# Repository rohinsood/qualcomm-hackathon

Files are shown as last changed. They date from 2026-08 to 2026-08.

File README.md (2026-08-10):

# Lighthouse 🔦 | Qualcomm Multiverse Hackathon Finalist

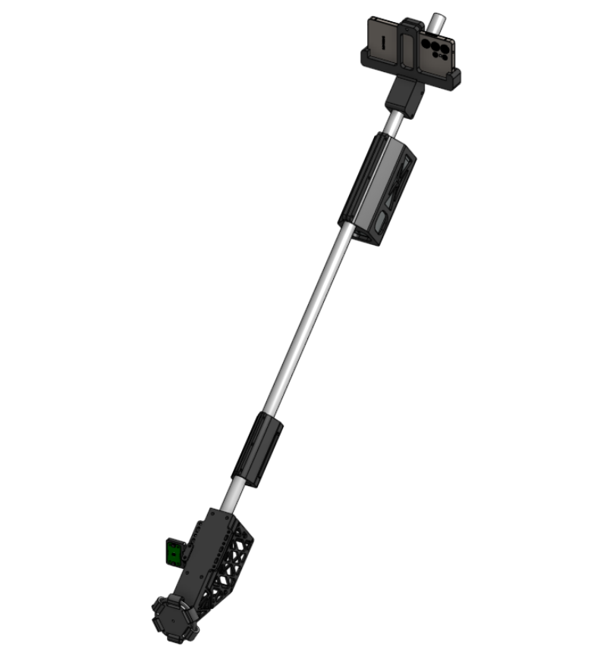
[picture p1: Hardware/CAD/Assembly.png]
|  |  |
:-------------------------:|:-------------------------:

**An open-source self-steering white cane powered by on-device AI.**

A 3D-printed omni wheel at the cane tip physically steers the user around
obstacles and along walking routes. All AI runs on Qualcomm silicon — no cloud,
no subscription, no signal required. Built, printed, assembled, and walked with.

**Demo Video**

https://github.com/user-attachments/assets/4f166f12-43d0-46fc-8983-bd9591bafe06

**Snapdragon Multiverse Hackathon 2026** · Qualcomm San Diego

| | |
|---|---|
| **~$196 total** | Excluding the phone. Commercial smart canes: $800–$1,150 |
| **No depth sensor** | Monocular metric depth on the Hexagon NPU replaces a LiDAR unit |
| **Fully offline** | Airplane mode changes nothing about obstacle avoidance |
| **AI across the Qualcomm multiverse** | Phone NPU/GPU + board CPU, running 8 models across 2 Snapdragon SoCs simultaneously |
| **Open source** | Code, CAD, BOM, wiring — AGPL-3.0 |

---

## Team

| Name | Github |
|---|---|
| Rohin Sood | https://github.com/rohinsood |
| Manuel Rodriguez | https://github.com/MaRodriguezB777 |
| Venkata Yaswanth Kanduri | https://github.com/kvyaswanth |
| Noah Zhang | https://github.com/iujab |

---

## Why this exists

250 million people live with impaired vision. A white cane costs $20 and tells
you nothing until you hit something. A guide dog costs $50,000 and has a
multi-year waitlist. Most electronic aids beep or buzz — interpreting that costs
time and attention at the exact moment you have neither.

Lighthouse **steers**. A motorized wheel nudges your hand toward the clear path.
You keep walking. The cane handles the geometry.

The key insight: steering the hand through the cane — grounded kinesthetic
feedback — guides people more accurately and with lower cognitive load than audio
or vibration cues. The NPU is what makes it possible to do the perception for
that steering on a phone, at the cadences required, on a battery.

---

## Accessibility first

- **Degrades to a white cane.** If every electronic system fails, contact sensing
  still works. The familiar form is kept deliberately.
- **Steering, not beeping.** Hearing stays free for traffic and conversation.
- **Offline by default.** No account, no connectivity, no privacy cost.
- **Private by construction.** Camera, audio, and location never leave the device.
- **Power on and walk.** No configuration needed to avoid obstacles.
- **Printable.** No proprietary parts. Break a piece, print another.
- **Refuses rather than guesses.** No corridor found → STOP, not a random direction.

---

## Edge AI on the Qualcomm stack

AI runs on **two Qualcomm SoCs simultaneously** — the phone's Snapdragon 8 Elite
(NPU + GPU) handles high-framerate vision, while the Arduino UNO Q's Dragonwing
QRB2210 (4×A53 CPU) runs a terrain classifier and a depth navigator on a
downward-facing camera at the cane handle. Different models, different devices,
different parts of the problem — all on Qualcomm silicon, all offline.

### Models running across the system

**Phone — Snapdragon 8 Elite (Hexagon NPU + Adreno GPU):**

| Model | What it does | Cadence | Accelerator |
|---|---|---|---|
| **Depth-Anything-V2-Metric-Small** | Per-pixel distance in meters | ~3 Hz | QNN → Adreno GPU / Hexagon NPU |
| **FFNet-78S-LowRes** (Cityscapes) | Walkability segmentation, outdoor | every frame | QNN → Hexagon NPU |
| **SegFormer-B0** (ADE20K) | Walkability segmentation, indoor | every frame | QNN → Hexagon NPU |
| **YOLOv8n** | Object detection + depth-scale calibration | 1 Hz | QNN EP |
| **Qwen3.5-2B** (Q4_0 GGUF) | On-device scene companion | on request | GenieX → Hexagon NPU |
| **Kokoro-82M** | Neural text-to-speech | on utterance | sherpa-onnx, CPU |

**Board — Dragonwing QRB2210 (4×Cortex-A53 @ 2 GHz):**

| Model | What it does | Cadence | Runtime |
|---|---|---|---|
| **Places365 ResNet18** | Terrain classification → 6-class taxonomy | ~2.3 fps | ONNX Runtime, CPU |
| **Depth-Anything-V2-Small** (126×126) | Ground-cam depth navigator | ~2.2 fps | ONNX Runtime, CPU |

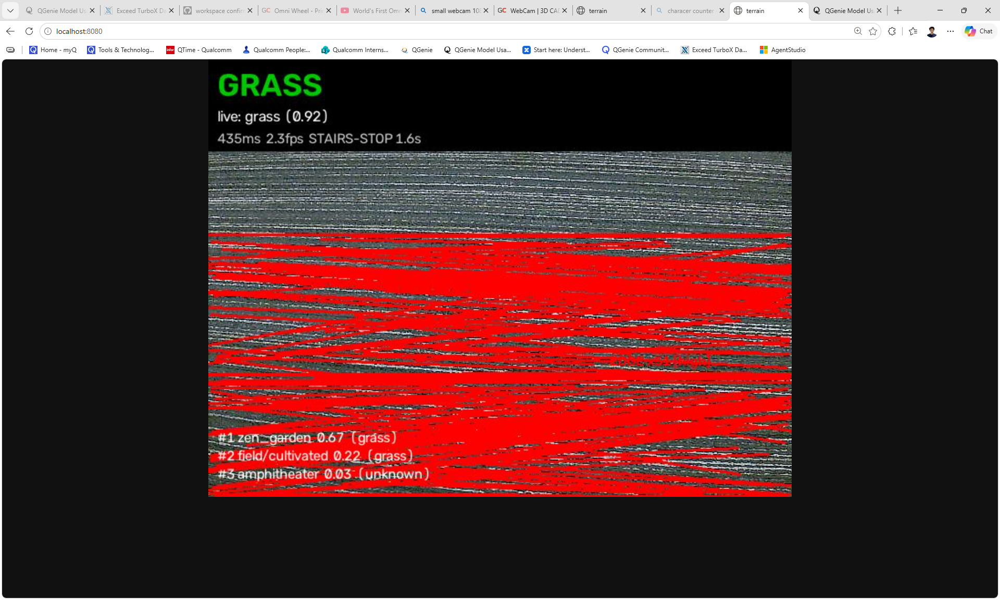
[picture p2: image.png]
Terrain classifier live


*Terrain sensor running on the UNO Q: Places365 classifying the ground surface
(GRASS, 0.92 confidence) at 435 ms / 2.3 fps, with Canny+Hough stair-edge
overlay in red. On a stairs detection, the wheel stops immediately and holds for
3 seconds — regardless of what the phone is asking for.*

### The terrain sensor — board-side AI that overrides the phone

The board's downward camera runs a **Places365 ResNet18** scene classifier
aggregated into a 6-class terrain taxonomy:

| Class | Meaning | Action |
|---|---|---|
| `sidewalk` | Walkable outdoor surface | → phone: OUTDOOR MODE |
| `road` | Vehicular surface | warn — user shouldn't be here |
| `grass` | Natural terrain | → phone: OUTDOOR MODE |
| `stairs` | Staircase / escalator / drop-off | **IMMEDIATE WHEEL STOP + 3 s hold** |
| `indoor_floor` | Interior walking surface | → phone: INDOOR MODE |
| `unknown` | Ambiguous | no action |

The stair-edge detector is a second signal: Canny + probabilistic Hough on the
lower 60% of the frame, looking for ≥5 parallel near-horizontal edges within 30%
of frame height. When it fires alongside the classifier, confidence is HIGH and
the stop is non-negotiable.

This is the one board-side motor command that **overrides the phone's steering
authority**. The phone drives the wheel left/right/clear — but STAIRS STOP takes
priority, because a staircase detected from the ground-facing camera is a
near-immediate hazard that the forward-facing phone may not see until the user is
at the edge.

The terrain label also **automatically switches the phone's nav mode** —
indoor_floor → indoor models (SegFormer + Hypersim depth), sidewalk/grass →
outdoor models (FFNet + VKITTI depth). No manual toggle needed.

### Accelerator allocation

```
QNN config: soc_model=69, htp_arch=79, burst mode, fp16
Fallback:   strict → mixed → CPU (never crashes, always runs)
```

**Vision takes the GPU first.** Not because it's faster — but because the
companion SLM decodes on the Hexagon NPU, and contending for it stalls the
safety-critical steering loop. Giving vision the Adreno GPU and reserving the NPU
for language keeps the critical path deterministic. This only matters when you're
running 6 models concurrently on one SoC.

**Domain-matched segmentation, not an ensemble.** FFNet-78S is trained on
Cityscapes (roads, sidewalks, curbs). SegFormer-B0 is trained on ADE20K (indoor
floors, doors, furniture). Running both every frame and merging was the earlier
design — it averaged away the specialization. Selecting one per nav mode halves
the compute for no measurable loss.

### Measured on-device

| What | Device | Result |
|---|---|---|
| Companion SLM first token (Qwen3.5-2B, Hexagon) | S25 Ultra | **186 ms** |
| Companion SLM decode rate | S25 Ultra | **12.1 tok/s** |
| Terrain classifier (Places365 ResNet18) | UNO Q | **435 ms / 2.3 fps** |
| Depth navigator (DA-V2, 126×126) | UNO Q | **452 ms / 2.2 fps** |
| Depth at higher res (DA-V2, 252×252) | UNO Q | 1728 ms — too slow for steering |
| MiDaS int8 on CPU | UNO Q | 1001 ms — **slower than float** (no NPU = dequant overhead) |

The board rows show why the split exists: the UNO Q runs terrain classification
and near-field depth at viable rates, but the high-res depth needed for corridor
planning at >3 Hz requires the phone's NPU. Each device does what it's good at.

### Qualcomm tooling

| Tool | Role |
|---|---|
| **QNN / QAIRT EP** | All phone vision inference, three-tier fallback |
| **Qualcomm AI Hub** | Sourced FFNet-78S and SegFormer-B0 |
| **GenieX** | On-device LLM runtime (Qwen3.5-2B) |
| **QUAD MCP** | Profiled models on real silicon over ADB |
| **Hexagon NPU** | Seg, depth, SLM decode on the phone |
| **Adreno GPU** | Vision (preferred tier) on the phone |
| **Arduino UNO Q** (Dragonwing QRB2210) | Terrain classification + ground-cam depth + actuation |
| **ONNX Runtime on QRB2210** | Board-side inference (Places365, DA-V2) at ~2.3 fps |
| **Arduino UNO Q** (Dragonwing QRB2210) | Cane board — sensing and actuation |

---

## How it works

```
Galaxy S25 Ultra — Snapdragon 8 Elite
  │
  ├─ Camera ~11 Hz → gravity-upright → 640×640 letterbox
  │    ├─ Depth-Anything-V2  @~3 Hz   metric depth (meters)
  │    ├─ Walkability seg    per-mode  FFNet outdoor / SegFormer indoor
  │    └─ YOLOv8n            @1 Hz    labels + depth-scale cal
  │         │
  │         └─ TraversabilityGrid  61×60 @ 0.1 m  log-odds  self-calibrating ground
  │              │
  │              └─ PolarPlanner  37 sectors ±90°  path-first  hysteresis
  │                   │
  │                   └─ CommandAggregator  200 ms vote → one letter
  │
  ├─ CompassNav  GPS + heading → goal bearing (Google routes or beeline)
  │
  └─ BLE ──► Arduino UNO Q — Dragonwing QRB2210
               ├─ Modulino Motors → omni wheel steers
               ├─ Modulino Distance → near-field STOP
               ├─ Modulino Vibro → haptic alert
               ├─ Ground camera → terrain.py (Places365 ResNet18)
               │    sidewalk/grass → OUTDOOR MODE
               │    indoor_floor → INDOOR MODE
               │    stairs → IMMEDIATE STOP + 3 s hold
               ├─ Ground camera → navigator.py (DA-V2 depth, 7-column)
               └─ 2 s failsafe
```

### Path-first planning

The planner is a **pass-through by default** — the route owns the heading.
Avoidance engages only when a ±10° cone around the goal is blocked.

- **Hysteresis:** blocks at 1.8 m, unblocks at 2.2 m — can't flip frame to frame
- **Committed heading:** `W_PREV = 1.6` > `W_GOAL = 1.0` > `W_WIDTH = 0.8` — the
  biggest weight resists changing its mind, which kills left-right oscillation
- **Asymmetric:** slow to leave the route (0.35), quick to return (0.45)
- **Refuses rather than guesses:** no corridor + no walkable columns → STOP

### Screen-thirds spoken guidance

An independent fallback, parallel to the planner: middle third decides whether
you can proceed, better outer third becomes the latched dodge side, spoken aloud
on each transition. Reuses data the pipeline already computes — no grid, no
planner involved.

---

## Hardware

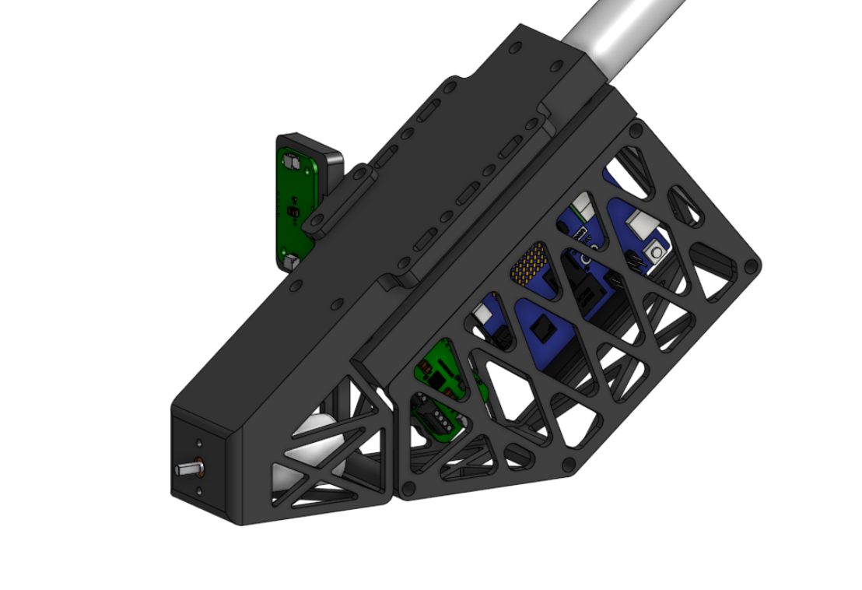
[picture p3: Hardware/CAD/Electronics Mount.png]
Electronics mount


Built, assembled, and walked with. ~$196 in parts, excluding the phone.

```
UNO Q ──► Modulino Motors ──► Modulino Vibro ──► Modulino Distance
```

| | |
|---|---|
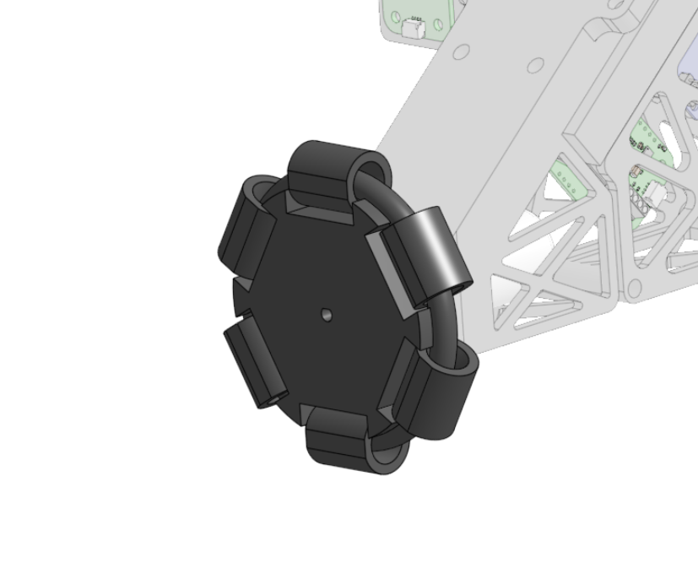
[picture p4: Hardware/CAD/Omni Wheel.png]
Omni wheel
|  | **Print-in-place omni wheel** — 6 rollers captive in the hub. No bearings, no assembly. Based on [this GrabCAD design](https://grabcad.com/library/omni-wheel-print-in-place-1), adapted for the JGA25 shaft. |
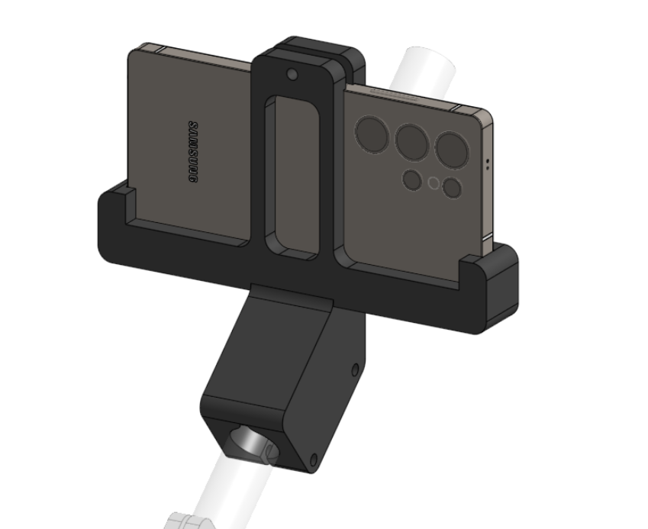
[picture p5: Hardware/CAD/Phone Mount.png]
Phone mount
|  | **S25 Ultra cradle** — pivoting hinge, rear cameras forward. |
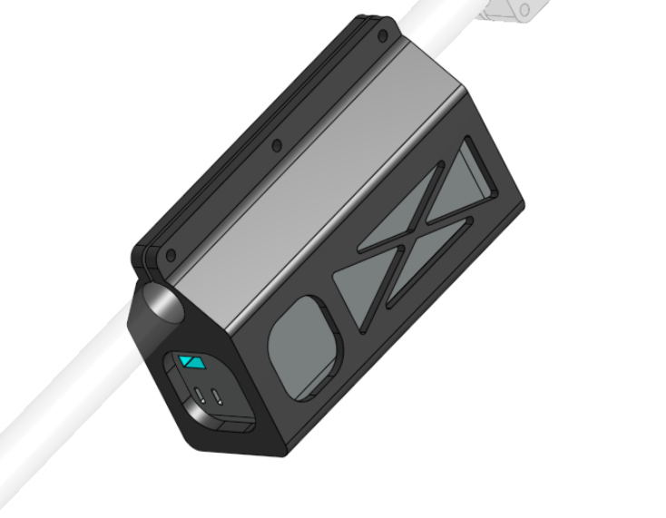
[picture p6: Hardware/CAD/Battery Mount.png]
Battery mount
|  | **Anker 737 cradle** — powers the board, charges the phone. |

**CAD source (Onshape):**
[open the live document](https://cad.onshape.com/documents/c0b905e8d1b94a52d9e9ca97/w/f6521fb190a4be4abaa604ca/e/e523a5a009f76747b4bb6591)

Full BOM and assembly: [`Hardware/`](Hardware/)

---

## Getting started

```bash
git clone https://github.com/<your-account>/lighthouse.git
cd lighthouse
git checkout v3
```

```bash
./gradlew :app:testDebugUnitTest     # 10 test classes, no device needed
./gradlew :app:installDebug
```

Models (depth + seg) must be pushed separately — see [`docs/MODELS.md`](docs/MODELS.md).
Board setup: [`docs/BOARD.md`](docs/BOARD.md).
Full from-scratch walkthrough: [`docs/SETUP.md`](docs/SETUP.md).

`main` also carries a merged demo (qhackGPS navigator + camera scan toggle) —
see [`docs/BRANCHES.md`](docs/BRANCHES.md).

---

## Repository layout

| Branch | What |
|---|---|
| **`main`** | Docs + hardware + merged demo app (qhackGPS + camera scan + voice) |
| **`v3`** | Full perception system — seg, depth, BEV grid, polar planner, SLM |
| `qhackfinal`, `qhackgps` | Nav prototypes and their lineage |

---

## Performance

| Parameter | Value |
|---|---|
| Perception cadence | 90 ms (~11 Hz) |
| Depth inference | 300 ms (~3 Hz) |
| Detection | 1000 ms (1 Hz) |
| Motor decisions | 200 ms (5 Hz) |
| Board failsafe | 2 s silence → motor stops |

Instrumented per-frame: `adb logcat -s ShepherdTime`

---

## Safety

**Research prototype. Not a sole mobility aid. Test with a sighted companion.**

| Guard | Threshold |
|---|---|
| Board motor failsafe | 2 s |
| Phone STOP on stalled vision | 600 ms |
| BLE write-stall teardown | 4 s |
| Planner can't find corridor | immediate STOP |

---

## Roadmap

**Done:** metric depth on NPU · domain-matched seg · BEV log-odds grid ·
path-first planner · walking routes + reroute · BLE steering · near-field ToF ·
terrain classification with stair-edge detection · automatic indoor/outdoor mode
switching · ground-cam depth navigator · neural TTS · on-device STT · OCR ·
screen-thirds spoken guidance · 2B companion on Hexagon · full CAD · cane built
and walked with

**Next:** end-to-end latency measurement · battery life characterization ·
companion model thermal gating · moving-obstacle prediction · user evaluation

---

## Prior work and acknowledgments

The steering concept — a motorized omni wheel applying grounded kinesthetic
feedback — is based on:

> P. Slade, A. Tambe, M. J. Kochenderfer, "Multimodal sensing and intuitive
> steering assistance improve navigation and mobility for people with impaired
> vision," *Science Robotics* **6**(59), eabg6594 (2021).
> [doi:10.1126/scirobotics.abg6594](https://doi.org/10.1126/scirobotics.abg6594)

Their study showed +18% walking speed for participants with impaired vision vs. a
white cane. Those are their results for their device — not a claim about ours.
Lighthouse is an independent implementation, not affiliated with the authors or
Stanford.

Also: [GrabCAD print-in-place omni wheel](https://grabcad.com/library/omni-wheel-print-in-place-1) ·
Qualcomm (NPU, QNN, AI Hub, GenieX, QUAD) · Arduino (UNO Q, Modulinos) ·
Depth-Anything-V2, FFNet, SegFormer, ONNX Runtime, sherpa-onnx.

## License

**AGPL-3.0** — see [`LICENSE`](LICENSE). Set by the bundled YOLOv8n detector.
Full reasoning: [`NOTICE.md`](NOTICE.md).

Open hardware, open software. Build it, change it, share it.

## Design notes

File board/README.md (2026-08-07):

# Cane board (Arduino UNO Q)

One app runs the whole cane: **`distance-watch/`** — phone-steered wheel,
obstacle haptics, LED-matrix status, and a live web dashboard. This is the
merged v3 firmware (wheel + three Modulinos + dashboard) carried onto the
qhackGPS/qhackcane pairing: the phone side here is **qhackGPS** (repo root),
talking over the Nordic UART bridge.

- **Wheel**: spins left/right on phone command or the dashboard buttons
  (dashboard always drives full scale). The 13×8 LED matrix mirrors the
  motion.
- **Vibro buzz**, parking-sensor style: pulses start at a 700 ms rhythm at
  the presence threshold (default 300 mm) and tighten to 250 ms as the
  obstacle closes; at/below 250 mm the buzz goes **continuous** ("stop now").
- **QCane Link dashboard** (port 7000): per-Modulino cards — distance
  readings (mm/cm, rate, age), motor telemetry with **live graphs** of
  sensed current (mA) and applied voltage (duty × VM, VM = 5 V), vibro
  state, Bluetooth links, rolling event log — plus manual spin/stop/buzz
  and clear-graphs buttons. Laptop arrow keys drive too: hold ← / → to
  spin (release stops), ↓/Space stops, ↑ buzzes.
- **Failsafe**: the Linux side re-sends the desired state 4×/s; if that
  stream stops for 2 s, the sketch stops the wheel and vibro on its own.

## Hardware

Modulinos daisy-chained on the Qwiic connector (`Wire1`), in wiring order:

```
UNO Q ──▶ Modulino Motors ──▶ Modulino Vibro ──▶ Modulino Distance
```

Chain order does not matter on I²C — each node answers on its own address.

**Motor wiring (important):** the motor sits across screw terminals
**`1A` + `2A`** — one half-bridge from **channel A** and one from
**channel B**, not a single channel's own pair, so the sketch drives the two
channels in opposite phase (`driveMotor()`); both channels show current
while it spins. `motor_selftest` re-measures every drive option if the
wiring is ever in doubt. Motor power goes into the `VM` + `GND` screw
terminals (5 V here); the yellow VM LED confirms power.

## How it works

```
Modulino Distance ──I²C──▶ MCU sketch ──"distance_reading"──▶ Python ──WebSocket──▶ dashboard
Modulino Motors + Vibro ◀──I²C── MCU sketch ◀──"set_wheel"/"set_vibro" heartbeat── Python
                                                                 ▲
                                                   HTTP :7000 (poll + POST)
                                                                 ▼
qhackGPS phone (BLE central) ◀──Nordic UART──▶ ble-bridge/ble_bridge.py (host daemon)
```

- `distance-watch/sketch/sketch.ino` — owns all three Modulinos: streams
  each valid ToF measurement, applies wheel commands (opposite-phase drive +
  matrix animation + `wheel_applied` acks), pulses the vibro, sends 2 Hz
  `motor_telemetry` and 1 Hz status heartbeats, and runs the motor
  self-test on request.
- `distance-watch/python/main.py` — the policy layer: presence
  (`mm <= threshold`) drives the vibro; the last wheel command (phone or
  dashboard, last writer wins) drives the motor; both re-sent 4×/s as the
  failsafe heartbeat. Serves the dashboard, REST API, event log, and graph
  history.
- `ble-bridge/` — host-side Nordic UART bridge + auto-accept pairing agent
  (systemd user services). The phone's texts steer the wheel (table below)
  and its 5 s heartbeat feeds the dashboard's Bluetooth card.
- `distance-watch/host/qcane_btd.py` — optional QCane GATT/SPP daemon from
  the v3 wheel board (speeds 1–5, `left`/`right 4`/JSON). Not needed for
  qhackGPS; the app's socket client simply reports "not running" until the
  daemon is started. Contract: `distance-watch/README.md`.

## Bluetooth (qhackGPS phone link)

`ble-bridge/ble_bridge.py` runs **on the Linux host** as a systemd *user*
service and exposes a standard **Nordic UART Service** peripheral named
**"Distance Watch"**:

| | UUID |
|---|---|
| Service (NUS) | `6E400001-B5A3-F393-E0A9-E50E24DCCA9E` |
| RX — phone **writes** | `6E400002-B5A3-F393-E0A9-E50E24DCCA9E` |
| TX — board **notifies** | `6E400003-B5A3-F393-E0A9-E50E24DCCA9E` |

**Board → phone** (subscribe to TX): `{"mm":123,"p":1}` — latest distance
and whether an obstruction is inside the threshold (`"mm":null` when nothing
is in range); `{"say":"..."}` — a line for the phone to read aloud over TTS,
sent whenever a dashboard button (spin/stop/buzz) is pressed.

**Phone → board** (write UTF-8 text to RX):

| you send | effect |
|---|---|
| a number, e.g. `1200` | sets the presence threshold (mm); ack `{"thr":1200}` |
| `get` | state snapshot as JSON |
| `TURN LEFT 90` / `TURN RIGHT 35` | route turn: wheel turns that way at full speed |
| other text containing `left` / `right` | full-speed dodge (e.g. `AVOID LEFT`) |
| text containing `clear` / `stop` / `straight` | stops the wheel |
| any other text | shown on the dashboard as "message from phone" |

**qhackGPS** (repo root) is the primary client: it auto-discovers "Distance
Watch", subscribes to the distance stream, widens the threshold to 1200 mm
on connect, and streams its steering back — `AVOID LEFT`/`AVOID RIGHT`
while dodging an obstacle, `TURN LEFT/RIGHT <deg>` when the route itself
bends (a 90° corner starts the wheel turning the moment guidance calls it),
`CLEAR` when aligned — all of which physically drive the wheel. The wheel
also stops when the phone disconnects or the bridge dies.

## Steering authority: the phone, only the phone

The board never decides a turn on its own. An obstacle is only *sensed*
here — it streams to the phone as `{"mm","p"}` — and qhackGPS makes the
call, answering with `AVOID`/`TURN`/`CLEAR` texts that drive the wheel
(and speaking every turn it commands). With no phone connected the board
buzzes the vibro but the wheel stays put; dashboard buttons still work,
and the 2 s failsafe still stops everything if the link dies.

Service install (first time on a board; fix the path in the unit to match
where this repo lives):

```bash
sed "s|/home/arduino/dev/qualcomm-hackathon/board/ble-bridge|$(pwd)/ble-bridge|" ble-bridge/qhack-ble-bridge.service > ~/.config/systemd/user/qhack-ble-bridge.service
sed "s|/home/arduino/dev/qualcomm-hackathon/board/ble-bridge|$(pwd)/ble-bridge|" ble-bridge/qhack-bt-agent.service  > ~/.config/systemd/user/qhack-bt-agent.service
systemctl --user daemon-reload && systemctl --user enable --now qhack-ble-bridge qhack-bt-agent
```

(Needs `python3-dbus` + PyGObject: `sudo apt-get install -y python3-dbus`.)

## Run

```bash
arduino-app-cli app start <repo>/board/distance-watch
arduino-app-cli app logs  <repo>/board/distance-watch --follow
```

Then open `http://<board-ip>:7000`.

## API quick reference (dashboard buttons use these)

```bash
curl -s localhost:7000/api/state                                                            # everything
curl -X POST localhost:7000/api/motor  -H 'Content-Type: application/json' -d '{"dir":-1}'  # -1 left, 0 stop, 1 right (full speed)
curl -X POST localhost:7000/api/vibro  -H 'Content-Type: application/json' -d '{"ms":600}'  # one-shot buzz, 50–3000 ms
curl -X POST localhost:7000/api/threshold -H 'Content-Type: application/json' -d '{"mm":250}'
curl -X POST localhost:7000/api/graphs/clear                                                # wipe the motor graphs
```

## Ground-cam extras (`depth-spike/`)

Two standalone programs that read the board's USB webcam and drive the
running cane app through the API above. They are optional — the cane works
without them — and they share port `:8080`, so run **one at a time**:

```bash
python3 <repo>/board/depth-spike/navigator.py --cane-url http://127.0.0.1:7000
python3 <repo>/board/depth-spike/terrain.py   --cane-url http://127.0.0.1:7000
```

- **`navigator.py`** — ground-cam obstacle avoidance: Depth-Anything-V2-small
  at 126×126 (~2.2 fps on the four A53s), seven depth columns over the path
  band, a self-tuning "empty corridor" baseline, and one verdict per frame —
  STOP / LEFT / RIGHT / CLEAR. Debug MJPEG view plus `/stats` and
  `/calibrate` on `:8080`. By default the verdict goes out as `/api/phone`
  text, which the phone reads aloud; `--transport motor` drives `/api/motor`
  directly — standalone-demo use only, because it competes with the phone's
  steering (see "Steering authority" above).
- **`terrain.py`** — terrain sensor: a Places365 ResNet18 classifier
  (six-class taxonomy: sidewalk / road / grass / stairs / indoor_floor /
  unknown) plus a Canny+Hough stair-edge detector gated on it. Announces
  debounced surface changes via `/api/phone` ("INDOOR MODE", "OUTDOOR MODE",
  "STAIRS AHEAD") and, on a stairs signature, stops the wheel and
  double-buzzes the vibro, holding the stop for 3 s. A wheel *stop* is the
  one board-side motor command that never fights the phone's authority.

`terrain.py` needs a model that is **not in the repo**:
`depth-spike/models/places365/resnet18_places365.onnx` with
`categories_places365.txt` beside it. Export from the MIT CSAIL Places365
ResNet18 checkpoint (torchvision resnet18 with 365 outputs -> ONNX, opset
17); the categories file ships with the Places365 release. Missing files
fail loudly at startup. `navigator.py`'s model
(`models/depthanything/da_v2_small.onnx`) is already committed.

## Tuning

- `distance-watch/sketch/sketch.ino`: `COMMAND_TIMEOUT_MS` (failsafe, 2 s).
  There is no speed knob — every spin is pinned to 100% duty in the
  firmware itself (speed arguments on the wire are ignored).
- `distance-watch/python/main.py`: `PRESENCE_MAX_MM` (threshold, also
  settable live from the phone or `/api/threshold`),
  `VIBRO_PERIOD_FAR_MS` / `VIBRO_PERIOD_NEAR_MS` / `VIBRO_STOP_TIER_MM`
  (haptic rhythm grading), `MOTOR_VM_V` (5 V — scales the dashboard
  voltage graph).

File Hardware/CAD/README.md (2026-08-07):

# CAD

Six print-ready assemblies for the Lighthouse cane. All parts are original to
this project except the omni wheel, whose provenance is noted below.

**Live CAD (Onshape):**
<https://cad.onshape.com/documents/c0b905e8d1b94a52d9e9ca97/w/f6521fb190a4be4abaa604ca/e/e523a5a009f76747b4bb6591>

The Onshape document is the editable source of truth — open it to modify
dimensions, adapt the phone mount to another device, or export a different
format. The STLs here are exports of it, committed so the repository stands on
its own without an Onshape account.

Full assembly

## Parts

| Part | STL | Render | Purpose |
|---|---|---|---|
| **Omni wheel** | `Omni Wheel.stl` | `Omni Wheel.png` | Six-roller print-in-place omni wheel. Rollers captive in the hub — no bearings, no axles, no assembly. |
| **Main frame** | `Main.stl` | — | Lower assembly: motor, wheel, and ToF sensor at the cane tip. |
| **Hub mount + cover** | `Hub Mount - Hub Cover.stl` | `Hub Mount.png` | Clamps the drive assembly to the shaft. |
| **Electronics housing + cover** | `Mount & Electronics - Electronics Cover.stl` | `Electronics Mount.png` | Skeletonized enclosure for the UNO Q and Modulino stack. |
| **Distance mount** | `Mount & Electronics - Distance Mount.stl` | — | Aims the ToF sensor forward and down. |
| **Phone mount** | `S25 Ultra - Phone Mount.stl` | `Phone Mount.png` | S25 Ultra cradle on a pivoting hinge; rear cameras face forward. |
| **Battery mount** | `Anker 737 Power Bank - Battery Mount.stl` | `Battery Mount.png` | Anker 737 cradle, ports accessible. |

## Print settings

| | Recommendation |
|---|---|
| Material | **PETG** for structural parts (main frame, hub mount, phone mount) — a cane gets dropped and flexed. PLA is fine for covers. |
| Layer height | 0.2 mm |
| Perimeters | 4 on structural parts |
| Infill | 25–30% structural, 15% covers |
| Supports | None needed. **Do not use supports on the omni wheel** — they will fuse the rollers. |
| Filament | ~400–550 g for the full set (~$12–18) |

> **Printed and fitted.** All parts have been printed and fit-checked on the
> built cane. One caveat worth passing on: roller clearance on the print-in-place
> wheel is printer-dependent. If your rollers come off the bed fused and won't
> work free by hand, scale clearance up 0.05 mm and reprint. If you print these
> and have to adjust anything else, please open an issue — that feedback is more
> valuable to this project than most code contributions.

## The omni wheel

Omni wheel

Based on the open-source print-in-place omni wheel published on GrabCAD:

**<https://grabcad.com/library/omni-wheel-print-in-place-1>**

Adapted here for the JGA25 motor's 4 mm D-shaft and this cane's tip geometry.
Check the license terms on that page before redistributing the derived geometry —
we are citing the source, not asserting its terms.

Print it flat, no supports, 30–40 mm/s. Rollers come off the bed fused; work each
of the six free by hand. If they won't release, scale roller clearance up 0.05 mm
and reprint.

Why print-in-place matters beyond convenience: it removes a commercial omni wheel
($15–25), a machined hub adapter, roller bearings, and an assembly step. The
reference research design used a machined wheel-to-hub adapter. This is a
meaningful part of how the build lands under $200.

## Design notes

**Skeletonized housings.** Weight and airflow. Every gram sits at the end of a
lever the user holds for the length of a walk, and the UNO Q runs warm under
sustained inference load.

**Pivoting phone hinge.** Camera pitch is the one mounting parameter the software
cannot fully self-correct. The grid self-calibrates height and reads pitch and
roll live from gravity, but a camera aimed at sky or pavement gives it nothing to
work with. The hinge exists so pitch can be set once and locked.

**Balance.** Mount the battery opposite the electronics housing. An unbalanced
cane is fatiguing in a way a ten-minute bench test won't reveal.

**It is still a white cane.** The shaft is a standard white cane or 1.25 in PVC,
and contact sensing works unchanged if every electronic system fails. That
fallback is deliberate.

## Source files

The editable models live in the **Onshape document linked at the top of this
file** — that is the place to make changes. The STLs committed here are exports,
kept in-repo so the build is reproducible without an Onshape account.

Adapting the phone mount to a device other than the S25 Ultra is the most likely
modification anyone will want; the Onshape document is where to do it.

## Reference

The mechanical concept — a motorized omni wheel at the cane tip applying grounded
kinesthetic steering — follows:

> P. Slade, A. Tambe, M. J. Kochenderfer, "Multimodal sensing and intuitive
> steering assistance improve navigation and mobility for people with impaired
> vision," *Science Robotics* **6**(59), eabg6594 (2021).
> [doi:10.1126/scirobotics.abg6594](https://doi.org/10.1126/scirobotics.abg6594)
> · [reference design](https://github.com/pslade2/AugmentedCane)

Their published CAD is a useful cross-reference, though this build's geometry
differs throughout: different motor, printed rather than machined wheel
interface, and housings sized for the UNO Q and a phone rather than for a LiDAR
unit and onboard compute.

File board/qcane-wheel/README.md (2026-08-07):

# 🦯 qcane-wheel

Spins a wheel motor left or right from a Bluetooth command. The motor is a
**Modulino Motors** board on the Qwiic bus; the 13×8 LED matrix mirrors what it
is doing — a wheel spinning clockwise, counter-clockwise, or sitting still,
with a bar on the side it is turning towards.

**This is now the merged cane app** (absorbed the former `distance-watch`):
on top of the wheel it reads the **Modulino Distance** sensor, pulses the
**Modulino Vibro** while an object is inside the presence threshold, streams
telemetry to the **QCane Link dashboard** on port 7000 (per-module cards,
live current/voltage graphs, manual spin + buzz buttons), and stops every
output within 2 s if the Linux side goes quiet (failsafe). See
[`../README.md`](../README.md) for the full-system picture; everything below
documents the Bluetooth contract, which is unchanged.

Two Bluetooth transports are exposed at the same time — pick whichever is
easier on the phone side.

---

## Bluetooth contract

Board identity:

| | |
|---|---|
| Bluetooth name (pairing / SPP) | `QCane-Wheel` |
| BLE advertised name | `QCane` (short, so it fits beside the 128-bit UUID) |
| Adapter address | `14:B5:CD:EA:B7:99` |

### Commands

Case-insensitive, and the parser is deliberately forgiving. All of these mean
the same thing:

```
left            LEFT            l           turn_left       turn-left
right           RIGHT           r           turn_right      turn-right
stop            STOP            s           halt            brake
```

An optional speed of `1`–`5` (default `3`) may follow, separated by `:`, `=`,
`,` or a space. JSON works too:

```
left            left:5          left 5          {"action":"left","speed":5}
```

Out-of-range speeds are clamped; unknown words are rejected and logged.

### Option A — BLE GATT (no pairing needed)

| | |
|---|---|
| Service | `bcf2f193-f22b-4695-af5e-fd3b9caf4977` |
| Command characteristic | `bcf2f194-f22b-4695-af5e-fd3b9caf4977` — `write`, `write-without-response` |
| State characteristic | `bcf2f195-f22b-4695-af5e-fd3b9caf4977` — `read`, `notify` |

Write the command as plain UTF-8 bytes. The state characteristic reads back
`"<action>:<speed>"` (e.g. `left:5`) and notifies on every change — note this
reflects what the **MCU actually applied**, not merely what was requested.

Scan by service UUID rather than by name; the name is only advertised as a
convenience.

```kotlin
val SERVICE = UUID.fromString("bcf2f193-f22b-4695-af5e-fd3b9caf4977")
val CMD     = UUID.fromString("bcf2f194-f22b-4695-af5e-fd3b9caf4977")
val STATE   = UUID.fromString("bcf2f195-f22b-4695-af5e-fd3b9caf4977")

// Scan with ScanFilter.Builder().setServiceUuid(ParcelUuid(SERVICE)).build(),
// connectGatt(...), discoverServices(), then:
val chr = gatt.getService(SERVICE).getCharacteristic(CMD)

// Android 13+
gatt.writeCharacteristic(chr, "left".toByteArray(), WRITE_TYPE_DEFAULT)

// Android 12 and older
chr.value = "left".toByteArray()
gatt.writeCharacteristic(chr)
```

### Option B — Classic SPP / RFCOMM (simplest phone code)

| | |
|---|---|
| Service UUID | `00001101-0000-1000-8000-00805f9b34fb` (standard SPP) |
| Channel | assigned by BlueZ, found via SDP |

Pair with `QCane-Wheel` once from Android's Bluetooth settings — the board runs
a `NoInputNoOutput` agent that auto-accepts, so there is no PIN prompt. Then
it is an ordinary socket. Send one command per line.

```kotlin
val SPP = UUID.fromString("00001101-0000-1000-8000-00805F9B34FB")
val device = adapter.bondedDevices.first { it.name == "QCane-Wheel" }
val socket = device.createRfcommSocketToServiceRecord(SPP)
socket.connect()
socket.outputStream.write("left\n".toByteArray())
```

State comes back on the same socket as `"<action>:<speed>\n"`.

### Android permissions

`BLUETOOTH_CONNECT` for both transports, plus `BLUETOOTH_SCAN` for BLE
(Android 12+). On Android 11 and older, BLE scanning also needs
`ACCESS_FINE_LOCATION`. All are runtime permissions.

---

## How it fits together

```
Phone  ──BLE GATT write──┐
       ──SPP  RFCOMM  ───┤
                         ▼
   host/qcane_btd.py            Linux side, runs on the host (not in Docker)
     owns BlueZ over D-Bus
                         │  Unix socket  .run/qcane-bt.sock
                         ▼
   python/main.py               Linux side, runs in the app container
     Bridge.call("set_wheel", dir, speed)
                         │  Router Bridge
                         ▼
   sketch/sketch.ino            MCU — drives the motor, mirrors it on the matrix
     Bridge.notify("wheel_applied", dir, speed, motorReady)  ──► up to the phone
                         │  Qwiic / Wire1, I²C 0x48
                         ▼
   Modulino Motors              MAX22211 dual H-bridge
```

**Why the daemon is separate.** The app's Python runs in a container on a
Docker bridge network with no `/run/dbus` mount, where `AF_BLUETOOTH` fails
with `EAFNOSUPPORT`. It cannot reach BlueZ at all, and there is no Bluetooth
brick. So the radio is driven from the host and the two halves meet on a Unix
socket inside the app folder, which is already bind-mounted into the container
at `/app`. The daemon needs no root and no pip packages — BlueZ is driven over
D-Bus through the system `gi` (PyGObject) install.

Keeping Bluetooth in a long-lived host process also means a connected phone
survives `arduino-app-cli app restart` while you iterate on the app.

---

## Running it

The Arduino App is managed normally:

```bash
arduino-app-cli app start   ~/ArduinoApps/qcane-wheel
arduino-app-cli app logs    ~/ArduinoApps/qcane-wheel --follow
```

The Bluetooth daemon is a separate host process:

```bash
python3 ~/ArduinoApps/qcane-wheel/host/qcane_btd.py          # foreground
python3 ~/ArduinoApps/qcane-wheel/host/qcane_btd.py -v       # with debug logs
```

To start it automatically, install the bundled **user** service (no root):

```bash
mkdir -p ~/.config/systemd/user
cp ~/ArduinoApps/qcane-wheel/host/qcane-btd.service ~/.config/systemd/user/
systemctl --user daemon-reload
systemctl --user enable --now qcane-btd
loginctl enable-linger arduino        # so it survives logout / starts at boot
```

Useful flags: `--no-ble`, `--no-spp`, `--name`, `--ble-name`, `--adapter`.

While it runs, the adapter is made discoverable and renamed to `QCane-Wheel`;
both are restored when the daemon exits.

## Testing without a phone

The daemon can inject commands into itself, which exercises the whole chain
down to the MCU and waits for the sketch's acknowledgement:

```bash
cd ~/ArduinoApps/qcane-wheel
python3 host/qcane_btd.py --send left --speed 5
python3 host/qcane_btd.py --send right
python3 host/qcane_btd.py --send stop
python3 host/qcane_btd.py --watch          # live view of commands and state
python3 host/qcane_btd.py --selftest       # profile the motor wiring
```

`--send` prints `left (speed 5) acknowledged by the app` only once the MCU has
reported back, so a success there means the full path worked.

MCU serial output goes to `arduino-app-cli monitor`.

---

## The motor

**Modulino Motors** — MAX22211 dual H-bridge, Qwiic bus (`Wire1` on UNO Q),
I²C address `0x48`, up to 3.8 A per channel. Needs the `Arduino_Modulino`
library at **0.9.0 or newer**; the 0.7.0 bundled with the core has no
`ModulinoMotors` class. A sketch profile does not resolve transitive
dependencies, so `sketch/sketch.yaml` lists the whole sensor-driver set that
`Modulino.h` pulls in — dropping any of them breaks the build.

### Power

The Qwiic cable only carries 3.3 V logic. **The motor needs its own 5–24 V
supply on the Modulino's power terminals**, or the H-bridge will accept every
command and drive nothing.

### Wiring

The wheel is across terminals **1A** and **2A** — one half-bridge from channel
A and one from channel B, rather than a single channel's own pair. So the two
channels are driven in opposite phase:

```cpp
motors.setDcSpeedRaw(+raw, -raw);   // one way
motors.setDcSpeedRaw(-raw, +raw);   // the other
```

This also works unchanged if the motor is moved onto a single channel's pair
(1A/1B), so it is a safe default either way.

To change the feel, edit `SPEED_PERCENT` in `sketch/sketch.ino` — speeds 1..5
map to 30/45/60/80/100 % of full scale. If left and right come out swapped,
flip the sign in `driveMotor()`.

`driveMotor()` is called from `loop()` on every change, never from the Bridge
handler: that runs mid-RPC on the bridge thread, where blocking, I²C traffic
and logging are all unsafe.

### Checking the wiring

`--selftest` drives each channel pair in turn and reports the current each one
draws, which identifies the terminals the motor is actually on — only a channel
with the motor across it draws current.

```bash
python3 host/qcane_btd.py --selftest        # 40% duty
python3 host/qcane_btd.py --selftest 100    # full power
```

```
stage                   channel A    channel B  mode
idle                       0.6 mA       1.3 mA  dc
A+ only (1A/1B)            1.3 mA       1.3 mA  dc
...
```

The `mode` column reads back from the module, so `dc` confirms it is receiving
commands. Readings of 0.6–1.3 mA are the ADC noise floor — i.e. no current at
all. If every row looks like that while `mode` still says `dc`, the module is
listening but nothing is being driven: check the 5–24 V supply first, then that
the motor leads are properly clamped in the screw terminals.

If the Modulino does not answer on the bus at all, the app logs a warning on
every command and `--selftest` reports `no modulino found`.

## Layout

```
qcane-wheel/
├── app.yaml                 no bricks — Bluetooth is not one, and could not run here anyway
├── python/main.py           socket -> Router Bridge
├── sketch/sketch.ino        Modulino Motors drive + LED matrix status
├── sketch/sketch.yaml       pinned libraries (Modulino 0.9.0 + its deps)
├── host/qcane_btd.py        BLE GATT + Classic SPP, driven over BlueZ D-Bus
├── host/qcane-btd.service   optional systemd user unit
└── .run/                    runtime socket (gitignored)
```

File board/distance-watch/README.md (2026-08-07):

# 🦯 qcane-wheel

Spins a wheel motor left or right from a Bluetooth command. The motor is a
**Modulino Motors** board on the Qwiic bus; the 13×8 LED matrix mirrors what it
is doing — a wheel spinning clockwise, counter-clockwise, or sitting still,
with a bar on the side it is turning towards.

**This is now the merged cane app** — v3's `qcane-wheel`, which absorbed the
original `distance-watch` app, carried into this repo under the
`distance-watch` name:
on top of the wheel it reads the **Modulino Distance** sensor, pulses the
**Modulino Vibro** while an object is inside the presence threshold, streams
telemetry to the **QCane Link dashboard** on port 7000 (per-module cards,
live current/voltage graphs, manual spin + buzz buttons), and stops every
output within 2 s if the Linux side goes quiet (failsafe). See
[`../README.md`](../README.md) for the full-system picture; everything below
documents the Bluetooth contract, which is unchanged.

Two Bluetooth transports are exposed at the same time — pick whichever is
easier on the phone side.

---

## Bluetooth contract

Board identity:

| | |
|---|---|
| Bluetooth name (pairing / SPP) | `QCane-Wheel` |
| BLE advertised name | `QCane` (short, so it fits beside the 128-bit UUID) |
| Adapter address | `14:B5:CD:EA:B7:99` |

### Commands

Case-insensitive, and the parser is deliberately forgiving. All of these mean
the same thing:

```
left            LEFT            l           turn_left       turn-left
right           RIGHT           r           turn_right      turn-right
stop            STOP            s           halt            brake
```

An optional speed of `1`–`5` may follow, separated by `:`, `=`, `,` or a
space — it is accepted for compatibility and **ignored**: every spin runs
at full scale (100 % duty). JSON works too:

```
left            left:5          left 5          {"action":"left","speed":5}
```

Unknown words are rejected and logged.

### Option A — BLE GATT (no pairing needed)

| | |
|---|---|
| Service | `bcf2f193-f22b-4695-af5e-fd3b9caf4977` |
| Command characteristic | `bcf2f194-f22b-4695-af5e-fd3b9caf4977` — `write`, `write-without-response` |
| State characteristic | `bcf2f195-f22b-4695-af5e-fd3b9caf4977` — `read`, `notify` |

Write the command as plain UTF-8 bytes. The state characteristic reads back
`"<action>:<speed>"` (e.g. `left:5`) and notifies on every change — note this
reflects what the **MCU actually applied**, not merely what was requested.

Scan by service UUID rather than by name; the name is only advertised as a
convenience.

```kotlin
val SERVICE = UUID.fromString("bcf2f193-f22b-4695-af5e-fd3b9caf4977")
val CMD     = UUID.fromString("bcf2f194-f22b-4695-af5e-fd3b9caf4977")
val STATE   = UUID.fromString("bcf2f195-f22b-4695-af5e-fd3b9caf4977")

// Scan with ScanFilter.Builder().setServiceUuid(ParcelUuid(SERVICE)).build(),
// connectGatt(...), discoverServices(), then:
val chr = gatt.getService(SERVICE).getCharacteristic(CMD)

// Android 13+
gatt.writeCharacteristic(chr, "left".toByteArray(), WRITE_TYPE_DEFAULT)

// Android 12 and older
chr.value = "left".toByteArray()
gatt.writeCharacteristic(chr)
```

### Option B — Classic SPP / RFCOMM (simplest phone code)

| | |
|---|---|
| Service UUID | `00001101-0000-1000-8000-00805f9b34fb` (standard SPP) |
| Channel | assigned by BlueZ, found via SDP |

Pair with `QCane-Wheel` once from Android's Bluetooth settings — the board runs
a `NoInputNoOutput` agent that auto-accepts, so there is no PIN prompt. Then
it is an ordinary socket. Send one command per line.

```kotlin
val SPP = UUID.fromString("00001101-0000-1000-8000-00805F9B34FB")
val device = adapter.bondedDevices.first { it.name == "QCane-Wheel" }
val socket = device.createRfcommSocketToServiceRecord(SPP)
socket.connect()
socket.outputStream.write("left\n".toByteArray())
```

State comes back on the same socket as `"<action>:<speed>\n"`.

### Android permissions

`BLUETOOTH_CONNECT` for both transports, plus `BLUETOOTH_SCAN` for BLE
(Android 12+). On Android 11 and older, BLE scanning also needs
`ACCESS_FINE_LOCATION`. All are runtime permissions.

---

## How it fits together

```
Phone  ──BLE GATT write──┐
       ──SPP  RFCOMM  ───┤
                         ▼
   host/qcane_btd.py            Linux side, runs on the host (not in Docker)
     owns BlueZ over D-Bus
                         │  Unix socket  .run/qcane-bt.sock
                         ▼
   python/main.py               Linux side, runs in the app container
     Bridge.call("set_wheel", dir, speed)
                         │  Router Bridge
                         ▼
   sketch/sketch.ino            MCU — drives the motor, mirrors it on the matrix
     Bridge.notify("wheel_applied", dir, speed, motorReady)  ──► up to the phone
                         │  Qwiic / Wire1, I²C 0x48
                         ▼
   Modulino Motors              MAX22211 dual H-bridge
```

**Why the daemon is separate.** The app's Python runs in a container on a
Docker bridge network with no `/run/dbus` mount, where `AF_BLUETOOTH` fails
with `EAFNOSUPPORT`. It cannot reach BlueZ at all, and there is no Bluetooth
brick. So the radio is driven from the host and the two halves meet on a Unix
socket inside the app folder, which is already bind-mounted into the container
at `/app`. The daemon needs no root and no pip packages — BlueZ is driven over
D-Bus through the system `gi` (PyGObject) install.

Keeping Bluetooth in a long-lived host process also means a connected phone
survives `arduino-app-cli app restart` while you iterate on the app.

---

## Running it

The Arduino App is managed normally:

```bash
arduino-app-cli app start   <repo>/board/distance-watch
arduino-app-cli app logs    <repo>/board/distance-watch --follow
```

The Bluetooth daemon is a separate host process:

```bash
python3 <repo>/board/distance-watch/host/qcane_btd.py        # foreground
python3 <repo>/board/distance-watch/host/qcane_btd.py -v     # with debug logs
```

To start it automatically, install the bundled **user** service (no root):

```bash
mkdir -p ~/.config/systemd/user
cp <repo>/board/distance-watch/host/qcane-btd.service ~/.config/systemd/user/
systemctl --user daemon-reload
systemctl --user enable --now qcane-btd
loginctl enable-linger arduino        # so it survives logout / starts at boot
```

Useful flags: `--no-ble`, `--no-spp`, `--name`, `--ble-name`, `--adapter`.

While it runs, the adapter is made discoverable and renamed to `QCane-Wheel`;
both are restored when the daemon exits.

## Testing without a phone

The daemon can inject commands into itself, which exercises the whole chain
down to the MCU and waits for the sketch's acknowledgement:

```bash
cd <repo>/board/distance-watch
python3 host/qcane_btd.py --send left --speed 5
python3 host/qcane_btd.py --send right
python3 host/qcane_btd.py --send stop
python3 host/qcane_btd.py --watch          # live view of commands and state
python3 host/qcane_btd.py --selftest       # profile the motor wiring
```

`--send` prints `left (speed 5) acknowledged by the app` only once the MCU has
reported back, so a success there means the full path worked.

MCU serial output goes to `arduino-app-cli monitor`.

---

## The motor

**Modulino Motors** — MAX22211 dual H-bridge, Qwiic bus (`Wire1` on UNO Q),
I²C address `0x48`, up to 3.8 A per channel. Needs the `Arduino_Modulino`
library at **0.9.0 or newer**; the 0.7.0 bundled with the core has no
`ModulinoMotors` class. A sketch profile does not resolve transitive
dependencies, so `sketch/sketch.yaml` lists the whole sensor-driver set that
`Modulino.h` pulls in — dropping any of them breaks the build.

### Power

The Qwiic cable only carries 3.3 V logic. **The motor needs its own 5–24 V
supply on the Modulino's power terminals**, or the H-bridge will accept every
command and drive nothing.

### Wiring

The wheel is across terminals **1A** and **2A** — one half-bridge from channel
A and one from channel B, rather than a single channel's own pair. So the two
channels are driven in opposite phase:

```cpp
motors.setDcSpeedRaw(+raw, -raw);   // one way
motors.setDcSpeedRaw(-raw, +raw);   // the other
```

This also works unchanged if the motor is moved onto a single channel's pair
(1A/1B), so it is a safe default either way.

There is no speed table any more — every spin is pinned to 100 % duty in the
sketch (speed arguments on the wire are ignored). If left and right come out
swapped, flip the sign in `applyMotor()`.

`applyMotor()` is called from `loop()` on every change, never from the Bridge
handler: that runs mid-RPC on the bridge thread, where blocking, I²C traffic
and logging are all unsafe.

### Checking the wiring

`--selftest` drives each channel pair in turn and reports the current each one
draws, which identifies the terminals the motor is actually on — only a channel
with the motor across it draws current.

```bash
python3 host/qcane_btd.py --selftest        # always full scale — the sketch ignores any percent argument
```

```
stage                   channel A    channel B  mode
idle                       0.6 mA       1.3 mA  dc
A+ only (1A/1B)            1.3 mA       1.3 mA  dc
...
```

The `mode` column reads back from the module, so `dc` confirms it is receiving
commands. Readings of 0.6–1.3 mA are the ADC noise floor — i.e. no current at
all. If every row looks like that while `mode` still says `dc`, the module is
listening but nothing is being driven: check the 5–24 V supply first, then that
the motor leads are properly clamped in the screw terminals.

If the Modulino does not answer on the bus at all, the app logs a warning on
every command and `--selftest` reports `no modulino found`.

## Layout

```
distance-watch/
├── app.yaml                 one brick (arduino:web_ui, the dashboard) — Bluetooth is not one, and could not run here anyway
├── assets/                  QCane Link dashboard (served on :7000)
├── python/main.py           socket -> Router Bridge
├── sketch/sketch.ino        Modulino Motors drive + LED matrix status
├── sketch/sketch.yaml       pinned libraries (Modulino 0.9.0 + its deps)
├── host/qcane_btd.py        BLE GATT + Classic SPP, driven over BlueZ D-Bus
├── host/qcane-btd.service   optional systemd user unit
└── .run/                    runtime socket (gitignored)
```

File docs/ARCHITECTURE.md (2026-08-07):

# Lighthouse — Architecture

Lighthouse is an on-device navigation aid for blind and low-vision users. A
Snapdragon phone runs the whole perception and planning stack locally; a
cane-mounted Arduino UNO Q carries a time-of-flight sensor, a haptic vibro
module and a steering wheel motor, and talks to the phone over BLE.

Everything in this document is drawn from the code on `origin/v3`. Constant
names are the real identifiers, so every number below can be grepped.

> Note on naming: the Kotlin package is `dev.quad.shepherd` and the hub class
> is `ShepherdService` — the package retains an earlier working name for the
> project and was not renamed.

---

## 1. System overview

```
┌───────────────────────────────── PHONE (Snapdragon 8 Elite / SM8750) ─────────────────────────────────┐
│                                                                                                       │
│  CameraX ImageAnalysis                                    Sensors                                     │
│  (KEEP_ONLY_LATEST)                                       TYPE_GRAVITY ──► pitchRad, rollRad          │
│        │                                                  TYPE_ROTATION_VECTOR ─► headingDeg          │
│        ▼                                                  FusedLocation (1 Hz) ─► lat/lng             │
│  ┌──────────────────────────── FrameAnalyzer ────────────────────────────┐        │                   │
│  │ YUV → sensor-upright → gravity-upright → 640×640 letterbox            │        ▼                   │
│  │                                                                       │   ┌──────────────┐         │
│  │  DetectionEngine   YOLOv8    1 Hz   ─► labels / blackboard / scale    │   │  CompassNav  │         │
│  │  DepthEngine       DA-v2     3.3 Hz ─► metric depth (in / out model)  │   │ INDOOR beeline│        │
│  │  SegEngine         FFNet | SegFormer-ADE ─► walkability mask          │   │ OUTDOOR route │        │
│  └───────────┬───────────────────────────────────────┬───────────────────┘   └──────┬───────┘         │
│              │ depth + walkable                     │ segClearance                 │ goalAngleDeg    │
│              ▼                                      ▼                              ▼                 │
│      ┌────────────────────┐   accumulate    ┌──────────────────────────────────────────┐              │
│      │ TraversabilityGrid │◄──log-odds──────│              PathPipeline                │              │
│      │  61 × 60 @ 0.10 m  │                 │  (owns grid + planner, IMU/nav inputs)   │              │
│      │  ego-centric BEV   │────raycast─────►│              PolarPlanner                │              │
│      └────────▲───────────┘                 │  37 sectors / 180° · DEFAULT ⇄ AVOID     │              │
│               │ markNearObstacle            └───────────────────┬──────────────────────┘              │
│               │                                                 │ Plan(guidance, stop, avoiding)      │
│               │                          ┌──────────────────────▼──────────────────────┐             │
│               │                          │ ShepherdService.onFrame                     │             │
│               │                          │  SteerFusion (v1 fallback only)             │             │
│               │                          │  SceneBlackboard · HapticFeedback · UI      │             │
│               │                          │  CommandAggregator  ── 200 ms vote ──► L/R/S/X            │
│               │                          └──────────────────────┬──────────────────────┘             │
└───────────────┼─────────────────────────────────────────────────┼────────────────────────────────────┘
                │  CaneReading{mm, present}          motor letter │   BLE GATT (Nordic-UART-style)
                │  ◄── TX notify bcf2f195…                        └──► RX write bcf2f194…
┌───────────────┴───────────────────── CANE BOARD (Arduino UNO Q, "QCane") ─────────────────────────────┐
│  Linux side: qcane_btd.py / main.py   — GATT server, policy, dashboard :7000, re-sends state 4×/s     │
│                     │ Unix socket                                                                     │
│  MCU sketch (Wire1 Qwiic chain): Modulino Motors ─ Modulino Vibro ─ Modulino Distance (VL53L4CD)      │
│  COMMAND_TIMEOUT_MS = 2000 → all outputs off if the Linux side goes quiet                            │
└───────────────────────────────────────────────────────────────────────────────────────────────────────┘
```

**The control loop.** Every camera frame that survives the duty-cycle gate is
made gravity-upright and letterboxed to 640×640. Detection runs at 1 Hz, dense
metric depth at ~3.3 Hz, and segmentation alongside depth. Each depth frame is
projected through the camera model onto the ground plane and folded into a
persistent ego-centric bird's-eye-view log-odds grid — so steering rests on
accumulated world-space evidence rather than one frame's opinion. The polar
planner then raycasts that grid *every* frame (raycasts are cheap, inference is
not), producing a heading that in the normal case simply *is* the navigation
goal, and only deviates while the goal direction is actually obstructed. The
resulting guidance is voted into a single motor letter every 200 ms and written
over BLE to the cane, which independently fails safe if the phone stops
talking. The cane's ToF reading comes back the other way and is injected into
the grid as hard near-field evidence.

---

## 2. Frame pipeline

`FrameAnalyzer` (`app/src/main/java/dev/quad/shepherd/vision/FrameAnalyzer.kt`)
is a `ImageAnalysis.Analyzer` bound by `ShepherdService.bindCamera()`.

### CameraX configuration

| Setting | Value | Why |
|---|---|---|
| Backpressure | `STRATEGY_KEEP_ONLY_LATEST` | Guidance wants the *newest* view of the world; a queued frame is a stale frame. |
| Camera | `DEFAULT_BACK_CAMERA` | Chest/pocket-facing forward view. |
| Analyzer executor | single-thread `Executors.newSingleThreadExecutor()` | Serializes inference; the grid/planner state is then free of locks on the hot path. |
| Use cases | `Preview` + `ImageAnalysis` | Preview surface is attached late and identity-checked (see §8). |
| Service type | `FOREGROUND_SERVICE_TYPE_CAMERA` (`| _LOCATION` once granted) | Guidance must survive screen-off / in-pocket operation. |

### Gravity and orientation

The gravity sensor callback in `ShepherdService` derives both angles from the
raw accelerometer-free gravity vector:

```kotlin
pathPipeline.pitchRad = asin((gz / g).coerceIn(-1f, 1f))   // rear camera looks along -Z
pathPipeline.rollRad  = atan2(gx, gy)                       // 0 = upright portrait
```

`PathPipeline.gravityUprightDeg` snaps roll to the nearest 90° (normalising the
±270° wrap), and the analyzer pre-rotates the frame by `-gravityDeg` before
inference. The reason is concrete: the depth and segmentation networks are
**not rotation-invariant**, so a phone held landscape or upside down must still
present an upright world to them. What is left over —
`PathPipeline.residualRollRad()` = `rollRad` minus the snapped part — is *not*
thrown away; it is handed to the grid, which un-rolls image-plane coordinates
analytically (§4). Two-stage correction: coarse by bitmap rotation (cheap, keeps
the model in-domain), fine by math (exact, no resampling cost).

The overlay counter-rotates using `FrameResult.gravityDeg`, so the debug
rendering stays aligned with what the user sees.

### Letterboxing

The upright frame is scaled by `scale = 640 / max(w, h)` and centered into the
640×640 square with symmetric padding `padX`, `padY`, drawn over a black
`clearPaint` rect. `DetectionEngine.INPUT_SIZE = 640`.

Two consequences are handled explicitly:

1. **Boxes are mapped back**: `(d.x1 - padX) / scale`, clamped to frame bounds,
   so detections live in camera-frame pixel space downstream.
2. **The bars are poison for depth.** `maskLetterboxBars()` writes `Float.NaN`
   over every depth pixel that lands on padding. The code comment records why:
   the depth model *hallucinates geometry* for the black bars — up to 25% of the
   square — which would corrupt the grid projection, the ground-plane estimate,
   the near-field columns and the box medians. NaN is the right sentinel because
   it sorts last and fails `isFinite()` gates, so every downstream percentile or
   median degrades to "no signal" rather than to garbage.

### Cadences

| Constant | Value | Effective rate | Rationale (from the code) |
|---|---|---|---|
| `MIN_FRAME_INTERVAL_MS` | `90L` | ~11 fps ceiling on the whole analyzer | Back-to-back running on every camera frame "kept the GPU pinned and thermal-throttled the whole SoC — guidance needs 10 Hz, not 30". |
| `DEPTH_INTERVAL_MS` | `300L` | ~3.3 Hz | "Walls don't move at frame rate." Depth is the latency-critical model and gets the freed budget. |
| `DETECT_INTERVAL_MS` | `1000L` | 1 Hz | Steering no longer uses YOLO — the grid owns it. Boxes only feed labels, the `SceneBlackboard`, and the `DepthCalibrator` scale samples. Between runs `lastModelSpace` is reused. |
| `CommandAggregator.PERIOD_MS` | `200L` | 5 Hz motor letters | See §7. |
| Planner | every surviving frame | ~11 Hz | Raycasting a 61×60 grid is nearly free; re-planning is how a stale grid still yields a fresh heading. |

Other frame-level constants: `DEBUG_NEAR_M = 0.3f` / `DEBUG_FAR_M = 6.0f` fix
the debug colour ramp; `DepthEngine.CORRIDOR_TOP = 0.25f` /
`CORRIDOR_BOTTOM = 0.65f` bound the depth analysis band, reported back in
camera-frame Y as `corridorTop` / `corridorBottom`.

**Depth scale calibration.** When depth and detection ran on the *same* frame,
untruncated boxes (`d.y1 >= 8f`, `d.y2 <= size - 8f`) with a pinhole
`DistanceEstimator.estimate()` prior contribute `(model metres, reference
metres)` pairs to `DepthCalibrator`. The `runDetect` guard is deliberate: "stale
boxes against fresh depth mislead".

**Async ADE segmentation.** The SegFormer-ADE member runs on its own
`adeExecutor` single thread at `NORM_PRIORITY - 1`, guarded by `adeBusy`. In
NPU/CPU mixed mode it is far slower than FFNet, and inline it stalled the
depth → grid → plan hot path. Walkability is *soft* evidence, so a mask a few
hundred milliseconds stale is acceptable; the worker publishes `r.copyOf()`
because the engine reuses its output buffer.

---

## 3. Accelerator strategy

`OrtSessions` (`app/src/main/java/dev/quad/shepherd/vision/OrtSessions.kt`) is
the single session factory for all ONNX Runtime engines. It exists because of
one specific trap.

### The silent-CPU problem

When QNN fails to claim graph nodes, ONNX Runtime **silently runs the whole
session on CPU**. A session "created with QNN" therefore proves nothing. The
strict tiers set:

```kotlin
opts.addConfigEntry("session.disable_cpu_ep_fallback", "1")
```

which makes *session creation itself fail* unless the entire graph compiled for
that accelerator. Only sessions that clear that bar earn the bare `"NPU"` /
`"GPU"` provider labels surfaced in `ShepherdService.visionLabel`. This turns an
unfalsifiable claim into a measurable one.

### Tier ladder

`createTiers()` walks strict tiers first, then mixed, then plain CPU:

| Order | Tier | Strict? | Label on success |
|---|---|---|---|
| 1 | GPU (`libQnnGpu.so`) | yes | `GPU` |
| 2 | NPU (`libQnnHtp.so`) | yes | `NPU` |
| 3 | GPU | no | `GPU/CPU mixed` |
| 4 | NPU | no | `NPU/CPU mixed` |
| 5 | default `SessionOptions()` | — | `CPU` |

`createFromPath(..., preferNpu = true)` **flips** tiers 1↔2 and 3↔4, for models
with external-data weights whose `.data` file must resolve relative to the
`.onnx` path. `SegEngine` is the caller that opts in.

### Why GPU first for vision

The workload split is deliberate: **vision on the Adreno, the companion SLM on
the Hexagon.** The header records the measurement that forced this ordering —
when the NPU tier led, vision landed on the Hexagon and throttled Qwen's decode
from **~12 tok/s to ~5**. The accelerators must not share. `SegEngine` is the
exception that proves the rule: FFNet is tiny, and the GPU is already carrying
YOLO plus depth, so segmentation is the one workload that *should* live on the
Hexagon (`preferNpu = true`).

### HTP options

| Key | Value | Why |
|---|---|---|
| `backend_path` | `libQnnHtp.so` | Hexagon HTP backend. |
| `htp_performance_mode` | `burst` | Inference is bursty and latency-critical, not sustained. |
| `enable_htp_fp16_precision` | `1` | fp16 on HTP — depth/seg tolerate it, and it buys throughput. |
| `soc_model` | `69` | SM8750 (Snapdragon 8 Elite, incl. the `-AC` "for Galaxy" variant), from the AI Hub catalog. |
| `htp_arch` | `79` | Hexagon v79. |

The SoC is spelled out rather than auto-detected because QNN's auto-detection of
the SM8750-AC variant is unproven.

GPU is simply `backend_path = libQnnGpu.so`.

### Vendor-library gotchas (documented in the file header)

QNN's accelerator backends `dlopen` **vendor** libraries — `libcdsprpc.so` for
the Hexagon DSP, `libOpenCL.so` for Adreno — which Android blocks unless the
manifest declares them via `<uses-native-library>`. Without that, HTP fails with
`QNN_DEVICE_ERROR_INVALID_CONFIG`, GPU with
`QNN_COMMON_ERROR_PLATFORM_NOT_SUPPORTED`, and everything lands on CPU. The NPU
additionally needs `libQnnHtpV*Skel.so` extracted to disk
(`useLegacyPackaging`), because the DSP opens it by file *path*.

### Domain-matched model selection

`FrameAnalyzer.indoorMode` mirrors `CompassNav.mode` (re-synced every frame in
`ShepherdService.onFrame`) and selects *both* experts per domain:

| Mode | Depth | Segmentation | Walkable classes |
|---|---|---|---|
| INDOOR | `DepthEngine()` — Depth-Anything-v2, Hypersim fine-tune | `SegEngine.ADE` — SegFormer-B0, ADE20K, 512×512 in → 128×128 out, 150 classes, ImageNet norm, **async** | `3, 6, 9, 11, 13, 28, 52` (floor, road, grass, sidewalk, earth, rug, path) |
| OUTDOOR | `depth_anything_v2_outdoor.onnx` — VKITTI fine-tune | `SegEngine.FFNET` — FFNet-78S low-res, Cityscapes, 1024×512 in → 256×128 out, 19 classes, **inline** | `0, 1, 9` (road, sidewalk, terrain) |

Each falls back to whichever member actually loaded. The engineering win is
stated in the code: each expert on its own turf, and **half the seg compute of
the always-both ensemble** — the earlier design ran both members every depth
frame. A missing model file simply disables that member.

Note that the *walkability fusion* still merges whatever masks exist:
`mergedWalkable()` resamples each model's class map into depth-pixel geometry
(depth px → 640 letterbox → source frame → model output coords) and votes
`1` = either model says walkable, `0` = every available model says not,
`-1` = outside the frame / no opinion. `WalkableColumns.clearanceFromMask()`
consumes the merged view rather than FFNet alone, because "FFNet alone is
out-of-domain indoors and steered the fallback toward Cityscapes
hallucinations".

---

## 4. Traversability grid

`TraversabilityGrid` (`app/src/main/java/dev/quad/shepherd/path/TraversabilityGrid.kt`)
is pure Kotlin — no Android imports — so it is JVM unit-testable.

| Parameter | Value | Extent |
|---|---|---|
| `cellsWide` | `61` | ±3.05 m lateral (`halfWidthCells = 30`) |
| `cellsDeep` | `60` | 0 → 6.0 m forward |
| `cellMeters` | `0.1f` | 10 cm cells |

Frame convention: `x` = metres right of the camera, `z` = metres forward. Cell
index `i = iz * cellsWide + ix`. `logOdds > 0` leans obstacle, `< 0` leans free,
`0` unknown.

### Projection, step by step

`update(depth, depthW, depthH, walkable, pitchRad, cameraHeightM, hFovDeg, rollRad)`:

**Step 0 — decay.** `decay()` runs *first*, multiplying every cell by `DECAY`.

**Step 1 — intrinsics from FOV.** No camera calibration file is needed; the
focal length is derived from the declared horizontal field of view:

```
fx = depthW / (2 · tan(hFovDeg/2))      cx = depthW/2      cy = depthH/2
```

`PathPipeline.hFovDeg` defaults to `70f`. `fx` is reused for the vertical axis —
the depth map is square (`depth.size × depth.size`), so pixels are square.

**Step 2 — image → camera ray.** For pixel `(u, v)` at metric depth `d`:

```
xi = (u - cx) / fx · d        // metres right, image plane
yi = -((v - cy) / fx · d)     // metres up   (image v grows downward, hence the negation)
```

**Step 3 — un-roll, about the optical axis.** A tilted or sideways-propped
phone rotates the image about the optical axis; the residual roll left over
after the 90° bitmap snap is removed analytically:

```
xc   =  xi·cosR + yi·sinR
yUp  = -xi·sinR + yi·cosR
```

**Step 4 — pitch, about X.** Rotation order matters: **roll first, then
pitch.** Roll is a rotation about the *optical* axis, so it must be undone in
camera coordinates before the pitch rotation lifts the ray into the
gravity-aligned world frame:

```
yW = yUp·cosP - d·sinP        // world up
zW = yUp·sinP + d·cosP        // world forward
```

**Step 5 — height above ground.**

```
height = cameraHeightM + yW - groundOffset
```

`PathPipeline.cameraHeightM` defaults to `1.35f`. `groundOffset` is the
self-calibrated correction from below.

**Step 6 — bin.** Only `zW > 0` is kept (nothing behind the camera):

```
ix = 30 + round(xc / cellMeters)        iz = round(zW / cellMeters)
```

Out-of-range indices are dropped.

**Step 7 — classify and accumulate.** Iteration uses `SAMPLE_STRIDE = 2` in both
axes (a quarter of the pixels — the grid is 10 cm-quantised anyway, so denser
sampling buys nothing but heat), and only depths in
`MIN_DEPTH_M = 0.25f .. MAX_DEPTH_M = 8f` are considered.

### Log-odds model

| Constant | Value | Meaning |
|---|---|---|
| `L_OBSTACLE` | `0.9f` | Point between `OBSTACLE_MIN_HEIGHT_M` and `OBSTACLE_MAX_HEIGHT_M`. |
| `L_FREE` | `-0.4f` | Point at ground level with no seg objection. |
| `L_SOFT_OBSTACLE` | `0.35f` | Flat, but segmentation says *not* walkable. |
| `SOFT_CAP` | `0.55f` | Soft evidence is only applied while `logOdds[i] < SOFT_CAP`. |
| `L_CLAMP` | `4f` | Symmetric saturation, so old evidence can still be overturned. |
| `DECAY` | `0.94f` | Per-update multiplicative decay — ~0.5 s half-life at 11 Hz. |
| `OBSTACLE_MIN_HEIGHT_M` | `0.18f` | Above this counts as an obstacle. |
| `OBSTACLE_MAX_HEIGHT_M` | `2.3f` | Above this is overhead structure and ignored — but doorframes are kept. |
| `GROUND_TOLERANCE_M` | `0.16f` | `|height|` below this is ground level. |
| `OBSTACLE_THRESHOLD` | `0.7f` | `isObstacle()` — what the planner raycasts against. |

Heights that are neither obstacle-band nor ground-band (below-ground noise, or
overhead) contribute `0f` — explicitly *no* evidence rather than a guess.

The `SOFT_CAP` design is the important safety asymmetry. Segmentation-only
evidence saturates at `0.55f`, **below** `OBSTACLE_THRESHOLD = 0.7f`, so
segmentation can never on its own declare a cell blocking. The stated reason:
Cityscapes is out-of-domain indoors. Geometry gets a veto; semantics only gets a
vote. Combined with `DECAY` and `L_CLAMP`, this gives the intended property —
"same scene → same answer" by construction, since a single wobbly frame cannot
flip the map, while a genuinely changed world washes out in about half a second.

Ratio note: `L_OBSTACLE / |L_FREE| = 2.25`, i.e. obstacle evidence accumulates
faster than free evidence erases it. For a mobility aid, the asymmetry is the
point.

### Ground self-calibration

The nominal camera height is a guess, and the file records what a ±10 cm error
does: it "would reclassify the whole floor as an obstacle band". So the grid
estimates the ground plane from the depth frame itself, every update:

1. Sample on a *frame-relative* stride, `strideV = max(depthH/22, 3)` and
   `strideU = max(depthW/22, 3)`, offset by half a stride, into a 512-slot
   buffer. The stride is derived from frame size specifically so coverage spans
   the **whole** image — a fixed stride filled the sample cap from the top rows
   alone, and with the camera pitched at a desk the "ground" latched onto the
   desk surface, turning the entire room into an obstacle field.
2. Accept only finite depths in `0.25f .. 5f` (near-field, where the ground
   actually is).
3. Require `n >= 80` samples, sort, and take the **12th percentile**
   (`sorted[n * 12 / 100]`). A low percentile finds the floor even when the
   floor is a *minority* surface in the image — a mean or median would be
   dragged upward by walls and furniture.
4. Sanity-gate on `abs(p12) < 0.7f`, then EMA with α = `0.25f`:
   `groundOffsetEma += 0.25f * (p12 - groundOffsetEma)`; the first accepted
   sample seeds it directly (`groundOffsetInit`). One bad frame cannot repaint
   the map.

`groundOffsetEma` is exposed read-only and printed in the `ShepherdTime` log
line alongside the depth scale and chosen steering angle.

### Cane near-field fusion

```kotlin
fun markNearObstacle(distanceM: Float, bearingDeg: Float = 0f)
```

Polar → grid index (`ix` from `sin`, `iz` from `cos`), then
`logOdds[i] += L_OBSTACLE * 2` (= `1.8f`), clamped to `±L_CLAMP`. The **double
weight** is the point: the cane's ToF sensor is a direct physical measurement,
not a learned inference, so one reading should immediately push a cell past
`OBSTACLE_THRESHOLD` (0.7) — where a single camera observation at `0.9f` also
would, but is far more likely to be wrong.

`ShepherdService.startCaneLink()` drives this from the BLE flow whenever
`r.present == true && r.mm != null`, converting mm → m. The same event fires
`haptics.caneStop()`. The class doc notes this is also the plug-in point for the
planned cane-mounted short-range (0.25 m) depth sensor.

`renderDebug()` produces the ARGB BEV overlay with `z` flipped so far rows draw
at the top: red above `OBSTACLE_THRESHOLD`, green below `-0.4f`, amber above
`0.2f` (suspicious — the soft-obstacle band), dark slate for unknown.

---

## 5. Polar planner

`PolarPlanner` (`app/src/main/java/dev/quad/shepherd/path/PolarPlanner.kt`),
pure Kotlin, JVM-testable. This is the component that decides where the user is
told to walk, and it is deliberately **path-first**: the route owns the heading,
and vision only interrupts.

| Parameter | Value | Meaning |
|---|---|---|
| `sectors` | `37` | Sector count. |
| `maxRangeM` | `5.5f` | Raycast horizon. |
| `SPAN_DEG` | `180f` | Fan width ⇒ **5° per sector** (`180 / 36`). |
| `BLOCK_ENTER_M` | `1.8f` | Free distance below which a sector becomes blocked (matches the earlier ~2 m steering sensitivity). |
| `BLOCK_EXIT_M` | `2.2f` | Free distance a blocked sector must exceed to unblock — hysteresis. |
| `DANGER_M` | `1.05f` | Forward-cone distance below which severity is DANGER. |
| `CAUTION_M` | `2.2f` | …below which severity is CAUTION. |
| `MIN_VALLEY_SECTORS` | `3` | ~15°: narrower is not a walkable corridor. |
| `W_GOAL` | `1.0f` | Cost weight: deviation from the goal. |
| `W_PREV` | `1.6f` | Cost weight: deviation from the committed heading. |
| `W_WIDTH` | `0.8f` | Cost *reward*: valley width. |
| `COMMIT_ALPHA` | `0.35f` | Low-pass toward a chosen detour heading. |
| `RETURN_ALPHA` | `0.45f` | Faster low-pass back onto the path. |
| `STEER_FULL_DEG` | `60f` | Angle that maps to `steer = ±1`. |
| `FORWARD_CONE_DEG` | `16f` | Half-width of the severity cone. |
| `GOAL_CONE_DEG` | `10f` | Half-width of the "is the path clear" cone. |
| `RAY_START_M` | `0.15f` | Raycasts skip the first 15 cm. |

`sectorAngle(s) = -90 + 180·s/36`, negative = LEFT. `raycast()` marches in
`grid.cellMeters * 0.6f` = 6 cm steps from `RAY_START_M` and returns the first
radius where `grid.isObstacle(ix, iz)`, or `maxRangeM` — including when the ray
leaves the mapped area without hitting anything ("left the mapped area" is
treated as free, not as blocked).

### Per-plan sequence

**1. Free distance per sector.** `free[s] = raycast(grid, sectorAngle(s))`.

**2. Neighbour smoothing.** `sm[s] = 0.25·free[s-1] + 0.5·free[s] + 0.25·free[s+1]`
(edge-clamped). A single 5° ray threading a gap between two chair legs is not a
corridor; the triangular kernel makes "open" mean *locally* open.

**3. Blocked state, with hysteresis.**

```kotlin
blocked[s] = if (blocked[s]) sm[s] < BLOCK_EXIT_M else sm[s] < BLOCK_ENTER_M
```

This is a Schmitt trigger. Entering costs 1.8 m, leaving requires 2.2 m — a
**0.4 m dead band**. Without it, a sector sitting at exactly the threshold would
toggle blocked/free at the frame rate, and the whole downstream decision would
chatter. `blocked` is persistent instance state (`BooleanArray(sectors)`), so
the latch survives across frames.

**4. Forward-cone severity.** `nearestForward` = min `sm[s]` over
`|sectorAngle(s)| <= FORWARD_CONE_DEG` (16°). `nearest` is that value, reported
only when it is genuinely inside the horizon
(`< maxRangeM - 0.01f`) — the epsilon avoids reporting the sentinel as a
measurement.

**4b. The mode decision.** `goalFree` = min `sm[s]` over sectors within
`GOAL_CONE_DEG` (10°) of the goal angle, then:

```kotlin
avoiding = if (avoiding) goalFree < BLOCK_EXIT_M else goalFree < BLOCK_ENTER_M
```

The **same** hysteresis pair governs the mode latch as governs individual
sectors, so the planner cannot flip-flop at the boundary. This single line is
the architecture: the planner deviates *only while the direction the route
actually wants is obstructed*.

### DEFAULT mode — the path owns the heading

When `!avoiding`, the planner is a pass-through with a low-pass:

```kotlin
committedAngle += RETURN_ALPHA * (goal - committedAngle)
```

`RETURN_ALPHA = 0.45f` is deliberately larger than `COMMIT_ALPHA = 0.35f`:
re-centering onto the route after a detour ends should be *faster* than
committing to a detour was. Detours are expensive to enter and cheap to leave.

Severity is still computed from `nearestForward` (DANGER < 1.05 m, CAUTION <
2.2 m, else CLEAR), so the user still gets proximity feedback while walking a
clear route; when CLEAR, `nearestDistanceMeters` and `nearestLabel` are nulled
so nothing spurious reaches the blackboard. Steering is
`(committedAngle / STEER_FULL_DEG).coerceIn(-1f, 1f)`. The returned
`Plan` has `stop = false, avoiding = false`.

Note what does *not* happen here: no valley search, no cost function. In the
common case the planner burns 37 raycasts and returns the route bearing. That is
the intended behaviour — a local planner that second-guesses a good route on
every frame produces exactly the wandering, un-trustable guidance this design
avoids.

### AVOID mode — VFH+-style valley selection

**5. Find valleys.** A valley is a maximal contiguous run of `!blocked[s]`. The
loop runs `s in 0..sectors` (one past the end) so a run that reaches the last
sector is still closed and evaluated. Runs with `width < MIN_VALLEY_SECTORS`
(3 sectors ≈ 15°) are discarded outright.

**Candidate angle within a valley** — the valley is *shrunk by one sector step
on each side* before choosing:

```kotlin
val step = SPAN_DEG / (sectors - 1)          // 5°
val lo   = sectorAngle(runStart) + step
val hi   = sectorAngle(runEnd)   - step
val cand = if (lo <= hi) goal.coerceIn(lo, hi)
           else (sectorAngle(runStart) + sectorAngle(runEnd)) / 2f
```

Two ideas here. First, the inset: aiming at the literal edge sector of a valley
aims at the obstacle bounding it, so a 5° safety margin is trimmed from each
side. Second, `goal.coerceIn(lo, hi)` — within a valley the planner picks the
point **closest to the goal**, not the middle. If the route bearing already
falls inside this valley, the candidate *is* the route bearing. Only when the
inset collapses the interval (`lo > hi`, i.e. a valley barely wider than the
minimum) does it fall back to the geometric centre.

**Cost function:**

```kotlin
cost = W_GOAL  * abs(cand - goal)          / 90f
     + W_PREV  * abs(cand - committedAngle)/ 90f
     - W_WIDTH * width.toFloat()           / sectors
```

Each term is normalised — angles by 90° (the fan half-width), width by
`sectors` — so the weights are directly comparable.

- `W_GOAL = 1.0f` — get back to the route.
- `W_PREV = 1.6f` — **the largest weight**, and the reason detours are usable.
  Penalising deviation from the *previous* decision more heavily than deviation
  from the goal makes a detour **committed**: two near-identical frames cannot
  produce opposite decisions, because whichever side was chosen last frame now
  carries a 1.6× advantage. Without this term, a symmetric obstacle (a pole dead
  ahead, equal gaps left and right) makes the cost of left and right nearly
  equal, and sensor noise picks a different one every frame — the user is told
  "left, right, left, right" and stops trusting the device. Hysteresis on
  `blocked[]` fixes chatter at the *sector* level; `W_PREV` fixes it at the
  *decision* level.
- `W_WIDTH = 0.8f` — subtracted, so wider valleys are cheaper. A 5-sector gap
  and a 20-sector gap are both "passable", but the wide one tolerates
  localisation error, body sway, and a companion walking alongside. At
  `0.8/37 ≈ 0.0216` per sector, ~46 sectors of extra width would be needed to
  offset a full 90° goal deviation — so width is a genuine tiebreaker between
  comparable options, never a licence to walk away from the route.

The minimum-cost valley wins.

**7. Commit.** `committedAngle += COMMIT_ALPHA * (bestAngle - committedAngle)`.
The chosen angle is approached at 35% per frame rather than snapped, so the
steering command is continuous even when the winning valley changes.

Severity, `steer`, `threatColumns` are computed as in DEFAULT; the plan carries
`stop = false, avoiding = true`.

**6. Seg-column fallback (only when no valley exists).** Before ever stopping,
the planner consults `segClearance` — the projection-free image-space
walkable-fraction columns from `WalkableColumns` (`NUM_COLUMNS = 16`, sampled in
the body-height band `BAND_TOP = 0.35f .. BAND_BOTTOM = 0.90f`). The reasoning:
the geometric grid can be poisoned by a bad depth scale, a wrong camera height,
or a mis-estimated ground plane — the image-space channel involves *none* of
those, so when the two disagree, the grid is the more likely liar.

```kotlin
var bestFrac = 0.55f                 // must be CLEARLY open
for (c in seg.indices) {
    val lo = maxOf(0, c - 1); val hi = min(seg.size - 1, c + 1)
    val frac = (seg[lo..hi].sum()) / (hi - lo + 1)   // 3-neighbourhood mean
    if (frac > bestFrac) { bestFrac = frac; bestC = c }
}
```

The 3-column neighbourhood mean encodes the same insight as the sector
smoothing: "one noisy open column between two walls must not win — a walkable
direction is WIDE." The 0.55 floor is initialised *as* the running best, so a
column must beat it, not merely reach it. On success the column maps to an angle
via `(bestC / (seg.size - 1) - 0.5f) * segFovDeg` (`segFovDeg` is passed
`hFovDeg`, 70° by default), commits at `COMMIT_ALPHA`, and returns severity
**CAUTION** with `stop = false` — steer there cautiously rather than freezing.

Note the complementary safety rule in `WalkableColumns.clearanceFromMask()`: a
column where every pixel is `-1` (nobody has an opinion) reads `0f`, not `0.5f`
— "never steer into what nobody has seen."

**STOP.** Only when there is no geometric valley *and* no clearly-open
segmentation column does the planner stop: `committedAngle = 0f`, severity
DANGER, `steer = 0f`, `stop = true`, `avoiding = true`. Zeroing the committed
angle matters — on the next frame the planner restarts from centre rather than
resuming a stale detour that no longer exists.

### World-space anchoring

```kotlin
fun rotateFrame(deltaDeg: Float) {
    committedAngle = (committedAngle - deltaDeg).coerceIn(-90f, 90f)
}
```

`PathPipeline.plan()` computes the compass delta since the last plan, unwraps it
to ±180°, and calls this when `|delta| > 0.5f` (a deadband against compass
noise). The committed heading is camera-relative, so without this correction it
would travel *with* the camera: the user turns toward the arrow, and the arrow
keeps pointing the same amount further in the same direction, forever. Rotating
by `-delta` holds the recommendation fixed in **world** space, so turning toward
it actually satisfies it. `reset()` clears `blocked`, `committedAngle` and
`avoiding` together.

`threatColumns()` compresses the 37 sectors into the 9-column
(`GuidanceEngine.NUM_COLUMNS`) overlay bar, taking the **worst** (minimum) free
distance per column and normalising to `1 - worst/maxRangeM`.

---

## 6. Navigation

`CompassNav` (`app/src/main/java/dev/quad/shepherd/nav/CompassNav.kt`) has two
modes, both of which reduce to a single signed number for the planner.

| Mode | Goal source | Rationale |
|---|---|---|
| `Mode.INDOOR` | Straight-line compass bearing to the destination | GPS routing knows nothing about corridors, so inside a building the beeline is the honest signal. |
| `Mode.OUTDOOR` | `RoutesClient` walking route + `RouteTracker` look-ahead | Aims at a look-ahead point along the actual street path, with spoken turn cues, off-route rerouting and arrival. Falls back to the beeline when no route can be fetched. |

Mode also selects the perception loadout (§3) — `ShepherdService.onFrame` sets
`analyzer?.indoorMode` from `compassNav.mode` every frame — and is switchable by
voice ("indoor mode" / "inside mode", "outdoor mode" / "outside mode"), handled
before anything else in `ShepherdService.ask()`.

### Sensors and constants

| Constant | Value | Role |
|---|---|---|
| `FIX_INTERVAL_MS` | `1000L` | `PRIORITY_HIGH_ACCURACY` fused-location interval. |
| `ARRIVAL_M` | `12.0` | Crow-flies arrival radius; announces and stops. |
| route retry | `20_000` ms | A destination set before the first fix could not fetch a route; failed fetches retry silently from `onFix`. |
| sensor rate | `SENSOR_DELAY_UI` | `TYPE_ROTATION_VECTOR`, ~15 Hz. |

`headingDeg` is true heading: magnetic azimuth from the rotation matrix plus the
`GeomagneticField` declination for the first fix, wrapped to `[0, 360)`.
`startPassive()` brings heading and fixes up **without** a destination, so the
map arrow and the scene digest are live from app start.

### Route look-ahead

`trackerStep()` advances `RouteTracker` **once per GPS fix**, not on the ~15 Hz
compass stream that `recompute()` rides. Turn cues, arrival and off-route
strikes are position-driven events; pacing them on the compass would fire them
repeatedly from a standing start. The tracker returns `remainingMeters`,
`targetBearingDeg`, and an event: `ARRIVED` (speak + stop), `TURN_CUE` (speak
the cue), `OFF_ROUTE` (speak "Rerouting", `clearRoute()`, `fetchRoute()`).

### How `goalAngleDeg` is computed

`recompute()` runs on every heading update and every fix:

1. `Location.distanceBetween(here, dest)` → `distance`, `bearing` (normalised to
   `[0, 360)`).
2. If `distance <= ARRIVAL_M`, announce arrival and stop.
3. **Outdoor with a live route** (`mode == OUTDOOR && tracker != null &&
   !targetBearingDeg.isNaN()`): the target is the route look-ahead bearing.
4. **Otherwise** (indoor, or outdoor before/without a route): the target is the
   crow-flies `bearing`.
5. Either way:

```kotlin
goalAngleDeg = if (headingDeg.isNaN()) null else {
    var delta = target - headingDeg
    while (delta > 180f) delta -= 360f
    while (delta < -180f) delta += 360f
    delta
}
```

so `goalAngleDeg` is the **signed turn** the user must make, `null` while the
heading is unknown — which the planner reads as `goal = 0f`, i.e. straight ahead.

### How it reaches the planner

`ShepherdService.onFrame`, every frame:

```kotlin
pathPipeline.goalAngleDeg = compassNav.goalAngleDeg?.coerceIn(-90f, 90f)
pathPipeline.headingDeg   = compassNav.headingDeg
```

The `±90°` clamp matches the planner's 180° fan — a goal behind the user cannot
be represented as a sector, so it saturates at the edge and the user turns.
`PathPipeline` publishes these as `@Volatile`, written from the main thread and
read on the analysis thread; `plan()` then feeds `goalAngleDeg` into the cost
function and uses `headingDeg` for `rotateFrame()`. Destinations arrive from a
map tap (`setDestination`) or a geocoded spoken phrase (`setSpokenDestination`,
matched by the unanchored `NAV_START` regex so "hey, can you take me to…" also
works).

---

## 7. Command path

### SteerFusion

`SteerFusion` (`app/src/main/java/dev/quad/shepherd/guidance/SteerFusion.kt`)
adds the navigation bias to the obstacle steer, scaled down by proximity:

| Constant | Value | Meaning |
|---|---|---|
| `NEAR_M` | `0.8f` | At/below this obstacle distance, navigation influence is zero. |
| `FAR_M` | `3.0f` | At/above this, navigation has full influence. |

```kotlin
if (goalSteer == null) return g.steer
if (g.severity == DANGER) return g.steer          // navigation ignored outright
val proximity = when (val d = g.nearestDistanceMeters) {
    null -> if (g.severity == CLEAR) 0f else 0.5f  // unknown distance: assume mid
    else -> (1f - (d - NEAR_M) / (FAR_M - NEAR_M)).coerceIn(0f, 1f)
}
return (g.steer + goalSteer * (1f - proximity)).coerceIn(-1f, 1f)
```

The closer the obstacle, the less the route matters; in DANGER the route does
not matter at all.

**Important**: with the polar plan active this is bypassed. In
`ShepherdService.onFrame`:

```kotlin
val fused = if (result.plan != null) guidance
            else guidance.copy(steer = SteerFusion.fuse(guidance, compassNav.goalAngleDeg?.let { it / 60f }))
```

The goal is already *inside* the planner's cost function, so additive fusion on
top would double-count it. `SteerFusion` now serves only the v1 fallback path
(`GuidanceEngine`, used when no depth model loaded), where the `/ 60f` divisor
matches `STEER_FULL_DEG`.

### GuidanceEngine → CaneCommand

`CaneCommand.from(guidance)` maps the continuous steer to a discrete direction
with `DEAD_ZONE = 0.2f`:

| Condition | Direction |
|---|---|
| DANGER and `abs(steer) <= 0.2` | `STOP` |
| `steer < -0.2` | `LEFT` |
| `steer > +0.2` | `RIGHT` |
| otherwise | `STRAIGHT` |

Danger with a usable gap still steers; danger with *no* better gap is the only
thing that stops. The dead zone keeps the wheel centred through steer noise.

### CommandAggregator — the 200 ms vote

`CommandAggregator` (`app/src/main/java/dev/quad/shepherd/path/CommandAggregator.kt`),
pure Kotlin, `@Synchronized` on both entry points.

`offer(guidance)` is called once per processed frame (~11 Hz) and adds a
severity-weighted vote for the direction:

| Severity | Weight |
|---|---|
| `DANGER` | `3f` |
| `CAUTION` | `2f` |
| `CLEAR` | `1f` |

`ShepherdService.startMotorLoop()` runs a coroutine that `delay`s
`PERIOD_MS = 200L` and calls `decide()`, writing the letter to `caneLink`. So
roughly 2–3 frames vote per window, and a single DANGER frame outweighs two
CLEAR ones — the aggregation is not a popularity contest, it is risk-weighted.

**Tie-break is a safety order, not arbitrary.** All directions within `1e-6f` of
the max are collected, then the first match wins in the order:

```
STOP  >  LEFT  >  RIGHT  >  STRAIGHT
```

STOP beats turns, turns beat STRAIGHT. A tie is exactly the ambiguous case where
the conservative choice is correct.

**Wire letters** (BLE NUS write to the UNO Q, forwarded to the Motor Modulino):

| Letter | Direction |
|---|---|
| `L` | left |
| `R` | right |
| `S` | straight |
| `X` | stop |

**Empty-window failsafe.** The ~11 Hz frame cadence beats against the 200 ms
window, so an occasional empty window is *normal* — not a fault. Failing to STOP
on the first empty window would produce a stutter the user feels as random
braking. Instead:

```kotlin
if (winner() == null) {
    emptyStreak++
    if (emptyStreak >= maxEmptyStreak) lastLetter = 'X'   // maxEmptyStreak = 3
    return lastLetter                                     // else repeat last decision
}
```

Three consecutive empties (~600 ms) means a true vision stall, and the letter
becomes `X`. `lastLetter` is initialised to `'X'`, so the very first command
before any frame arrives is stop. The board's own timeout backstops the link
itself (§8). `ShepherdService` logs only on change (`lastMotorLetter`), so the
5 Hz write stream does not flood the log.

---

## 8. Failure modes and safety

### Timeouts and watchdogs

| Layer | Mechanism | Threshold | Behaviour |
|---|---|---|---|
| Aggregator | `maxEmptyStreak` | 3 empty 200 ms windows (~600 ms) | Motor letter → `X`; before that, repeat `lastLetter`. |
| BLE link | watchdog coroutine | polls every `3000L` ms | If `desired && gatt == null && !scanning`, restart the scan. |
| BLE link | `WRITE_STALL_MS` | `4_000L` ms in flight with no callback | **Zombie-link detection** — teardown, state → `Disconnected`, `reading` → null, rescan. Android does not always deliver `STATE_DISCONNECTED` (seen when the board reflashes its MCU, or after a Bluetooth toggle), so a live-looking `gatt` that no longer delivers callbacks must be detected by *behaviour*, not by state. |
| BLE link | `WRITE_FAIL_STREAK` | `8` consecutive immediate write failures | Declare the link dead, teardown, rescan. |
| BLE link | `SCAN_WINDOW_MS` | `10_000L` ms | Scans are duty-cycled off; the 3 s watchdog starts the next round. Continuous BLE scanning is a battery sink. |
| Cane board (MCU) | `COMMAND_TIMEOUT_MS` | `2000` ms | The Linux side re-sends desired actuator state **4×/s**; if that stream stops (app or bridge died), the wheel stops and the vibro goes quiet rather than run away. |
| Cane board (Linux) | `STALE_AFTER_S` | `1.0` s | Sensor readings older than this are stale. |
| Cane board | `MODULE_RETRY_MS` | `3000` ms | Re-init any Modulino that is not ready. |
| Cane board | `DISTANCE_POLL_MS` / `TELEMETRY_MS` | `20` / `500` ms | ToF poll rate; dashboard telemetry rate. |
| Haptics | `HapticFeedback.REPEAT_MS` | `1200L` ms | Rate-limits the cane STOP buzz. |
| Vibro rhythm | `VIBRO_PULSE_MS` / `VIBRO_PERIOD_MS` | `250` / `500` ms | A 250 ms buzz every 500 ms while an object is inside the presence threshold. Each pulse self-terminates, so a wedged Linux side cannot leave the motor on. |
| Presence | `OBSTACLE_THRESHOLD_MM` | `1200` mm | Pushed to the cane on connect. |
| v1 fallback | `DANGER_HOLD_MS` / `CAUTION_HOLD_MS` | `1000` / `800` ms | `GuidanceEngine` severity hold (`dangerDistance = 1.5f`, `cautionDistance = 3.0f`). |

Note the layering: three independent stages will stop the wheel — the
aggregator (~600 ms, phone-side vision stall), the BLE watchdog (3–4 s, link
death), and the MCU timeout (2 s, anything upstream dying, including the phone
being switched off). No single failure leaves the motor running.

### Graceful degradation

| Missing / failing | Result |
|---|---|
| YOLO model absent | `visionLabel = "no model"`, spoken `R.string.model_missing`, pipeline aborts (detection init gates all other engines). |
| Depth models absent | `PathPipeline` is not passed to the analyzer; `GuidanceEngine` v1 column pipeline takes over via `result.plan ?: guidanceEngine.update(...)`. |
| One seg model file absent | That member logs and disables itself; the other carries on. `mergedWalkable` handles a single non-null mask. |
| QNN unavailable | Tier ladder falls to `CPU` (§3); label reflects it. |
| No walking route | Beeline fallback, announced **once** (`routeFallbackAnnounced`), retried silently every 20 s. |
| Geocode failure | "I couldn't find *X* nearby." |
| No location permission | `compassNav.startPassive()` skipped; FGS type omits `_LOCATION` and is re-promoted via `startForeground` once nav is requested and permission exists. |
| Depth letterbox bars | NaN-masked; consumers see "no signal", not hallucinated geometry. |
| `< 80` ground samples, or `abs(p12) >= 0.7f` | Ground offset is not updated — the last EMA value persists rather than a bad frame being trusted. |
| Grid cell with no observations | `logOdds == 0` ⇒ not an obstacle ⇒ raycast passes; unknown is treated as traversable, and `DECAY` returns stale cells toward unknown. |

### Deliberate safety choices

- **Haptics are not driven from vision.** The only buzz is the cane sensor's
  STOP, so a vibration *always* means "obstacle at the cane", never routine
  steering. Overloading the one high-bandwidth non-auditory channel with
  routine information would destroy its meaning.
- **Nothing about obstacles is spoken.** DANGER *onsets* are recorded to the
  `SceneBlackboard` (`noteAlert`) so the companion can discuss them when asked,
  but the device does not narrate. Speech is reserved for navigation events and
  answers.
- **Preview detach is identity-checked.** On activity recreation the old
  instance's teardown runs *after* the new one attached; a blind
  `setSurfaceProvider(null)` blanked the fresh preview ("can't see the camera
  sometimes"). `detachPreview` now only clears if `attachedSurface === surfaceProvider`.
- **Foreground service, `START_STICKY`.** Camera, vision, guidance and speech
  all live in `ShepherdService`, so everything keeps working with the screen off
  or the phone in a pocket; `MainActivity` is a thin bound shell.
- **Thermal awareness.** `OnThermalStatusChangedListener` appends `" · warm"` to
  the status line at `THERMAL_STATUS_MODERATE` and above, and logs transitions.
  It is surfaced, not acted on — the duty-cycle constants are the actual
  mitigation.
- **`onDestroy` releases in dependency order**: thermal listener, gravity
  listener, nav, BLE, chat, speech, OCR, actuator, analysis executor, then each
  ONNX session.

---

## 9. Known gaps

- **Companion SLM is parked.** `ShepherdService.COMPANION_ENABLED = false`. The
  NPU, memory and thermal budget goes to perception instead. Voice navigation
  intents and OCR reading never touched the SLM and keep working; with the flag
  off, a non-OCR question gets "The companion is off. Say, take me to, followed
  by a place, to navigate." `warmChat()` returns immediately. Flipping the flag
  to `true` restores it — and reintroduces the Adreno/Hexagon contention that
  §3's tier ordering exists to manage.
- **`CaneActuator` is a stub.** `ShepherdService` instantiates `NoOpActuator()`.
  The real BLE path to the cane is `CaneBleLink` + `CommandAggregator`;
  `CaneActuator.kt` still carries `TODO` comments for
  `BluetoothLeScanner → connectGatt → discoverServices` and
  `gatt.writeCharacteristic(...)`. `actuator.sendGuidance(fused)` is therefore a
  no-op today, and the file's own comment says to wire a BLE implementation.
- **Cane depth sensor not present.** `TraversabilityGrid.markNearObstacle` is
  built and wired, but only the ToF distance reading uses it; the documented
  "forthcoming cane-mounted short-range depth sensor (0.25 m)" is not shipped.
  `bearingDeg` defaults to `0f`, so every cane reading lands dead ahead — the
  sensor provides no bearing.
- **Grid is narrower than the planner's reach.** With `cellsWide = 61` at
  `0.1 m`, the lateral half-extent is 3.05 m, while `maxRangeM` is 5.5 m. Rays
  toward the fan edges leave the mapped area before the horizon and `raycast`
  returns `maxRangeM` — reported as fully free. Peripheral sectors are therefore
  optimistic by construction. The forward extent (6.0 m > 5.5 m) is fine.
- **`hFovDeg` and `cameraHeightM` are constants, not measurements.**
  `PathPipeline` defaults to `70f` and `1.35f` with no per-device calibration.
  Ground self-calibration absorbs height error, and `WalkableColumns` provides a
  projection-free cross-check, but a wrong FOV scales `fx` and therefore the
  whole lateral projection with nothing to correct it.
- **`pitchRad` initial value is a guess** (`0.30f`) until the first
  `TYPE_GRAVITY` event.
- **Detections do not feed the grid.** YOLO boxes contribute labels, blackboard
  content, and depth-scale samples only. A recognised obstacle class is not
  written into the traversability map.
- **`DepthCalibrator` needs cooperating scenes.** Scale samples require an
  untruncated detection of a known-height class in the same frame as a depth
  run; in a corridor with no people or furniture the raw metric output is used
  as-is (`calibrator.convert(raw) ?: raw`).
- **`FrameAnalyzer` allocates per frame.** `metricDepth()` builds a fresh
  `FloatArray(depth.size²)` and `mergedWalkable()` a fresh `ByteArray` on every
  depth frame; the letterbox bitmap and input tensor are pooled, these are not.
- **`Plan.sectorFreeM` aliases planner state.** `sm` is returned by reference in
  the `Plan`; it is not defensively copied.
- **`CommandAggregator.votes` is only cleared on a decisive window.** In the
  empty-window path `votes.clear()` is not reached — harmless because the window
  was empty, but the asymmetry is worth noting.
- **BLE bearing/telemetry is one-way for planning.** `CaneReading` carries `mm`
  and `present`; wheel telemetry (current, duty, applied direction) reaches the
  board dashboard on port 7000 but is not fed back into the planner as a control
  loop.

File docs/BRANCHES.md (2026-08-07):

# Branches

`main` began as a **documentation and hardware hub** — README, license,
`Hardware/`, `docs/` — with all application code on branches. Two merges
changed that. `main` now also carries a complete, runnable system:
**`qhackfinal`** merged wholesale (the qhackGPS phone app + the cane
firmware), plus one piece of **`v3`** — the screen-thirds camera scan —
ported into the app as a toggleable feature ([`SCAN.md`](SCAN.md)).

If you are here to run the merged demo, stay on `main`. If you are here for
the full perception stack — segmentation, depth, the BEV planner — you want
**`v3`**:

```bash
git checkout v3
```

---

## `main` — the merged demo system

```
app/                            Android app  (Kotlin, package com.example.qhackgps — "qhackGPS")
board/distance-watch/           Cane board app  (Arduino UNO Q: sketch + Python + web dashboard + QCane host daemon)
board/ble-bridge/               Nordic UART bridge the phone talks to  (advertises "Distance Watch")
board/depth-spike/              Depth bench + USB ground-cam navigator + terrain sensor  (bench: the experiment behind PERFORMANCE.md)
arduino/qhack_guidance_motor/   Older HC-05 SPP demo sketch, fed by the `QG,…` wire lines
Hardware/                       CAD, BOM, assembly
docs/                           this documentation
```

The app is a landscape map HUD: Google walking routes or straight-line
compass mode, alignment guidance with hysteresis and a persisted
heading-trim calibration, system-TTS voice on transitions, and phone-buzz
haptics while the cane reports an obstacle. A push-to-talk companion —
v3's Qwen SLM on the Hexagon NPU — answers questions grounded in what the
camera scan sees, reads signs on request, and takes spoken navigation
commands ("take me to…"). The **phone is the only
steering authority** — the board senses (ToF distance) and actuates (wheel,
vibro), but every turn is the phone's call, sent as `AVOID LEFT`/`AVOID
RIGHT` (full-speed dodge), `TURN LEFT|RIGHT <deg>` (route turn), or
`CLEAR`/`STOP` (wheel stop) and parsed by
`board/distance-watch/python/main.py`. The optional camera scan folds into
that same vocabulary; its precedence table is in [`SCAN.md`](SCAN.md).

The port from `v3` was **selective**: the thirds decision logic, the YOLO
detector plumbing, and the QNN session tiering came over
(`app/src/main/java/com/example/qhackgps/scan/`), followed by the
companion SLM with its push-to-talk voice loop and OCR (`…/llm/`,
`…/speech/`) and the board depth spike. The v3 app itself — package
`dev.quad.shepherd`, with the segmentation ensemble, metric depth, the
BEV planner, and the neural voice — was **not** merged and remains
complete on its branch.

## `v3` — the full perception system

The complete implementation. Both halves in one tree:

```
app/                     Android app  (Kotlin, package dev.quad.shepherd)
board/qcane-wheel/       Cane board app  (Arduino UNO Q: sketch + Python + host daemon)
board/ble-bridge/        Nordic UART side channel, for nRF-style debugging
board/depth-spike/       On-board depth benchmark — the experiment behind docs/PERFORMANCE.md
tools/walkability/       Offline planner evaluation harness (numpy mirror of the on-device pipeline)
scripts/                 Model export + fetch
```

Everything in [`ARCHITECTURE.md`](ARCHITECTURE.md), [`MODELS.md`](MODELS.md),
[`BOARD.md`](BOARD.md), and the measured numbers in
[`PERFORMANCE.md`](PERFORMANCE.md) describes **this branch** — not the app
on `main`. What `main` took from here: the screen-thirds decision logic
and the detector pipeline under it ([`SCAN.md`](SCAN.md)), the companion
SLM with its voice loop, and `board/depth-spike/`.

Two directories are worth knowing about even though they don't ship:

- **`board/depth-spike/`** — the CPU depth benchmark whose results are in
  [`PERFORMANCE.md`](PERFORMANCE.md). It's why depth runs on the phone.
- **`tools/walkability/`** — replays burst photos through a numpy mirror of
  `TraversabilityGrid` + `PolarPlanner`, scoring candidate pipelines by
  **angle spread** across a burst. Lower is better; that's decision jitter,
  measured offline before anything reaches the phone. Its constants must be kept
  in sync with the Kotlin by hand.

## `qhackfinal` — what `main` was merged from

The demo pairing, developed alongside `v3` rather than from it (`git
merge-base --is-ancestor` confirms `v3` is not in its history). It combined
`qhackgps` (the phone navigator) and `qhackcane` (the distance-sensor
board) into one branch (868b2c3), ported v3's merged wheel firmware into
`board/distance-watch/` (cd974fd), and then evolved the pair into the
system now on `main`:

- the phone became the **sole steering authority** (caffc03) — the board
  streams `{"mm","p"}` and obeys text, and never decides a turn;
- every wheel spin **pinned to 100 % duty** in the firmware, and the
  dashboard grew arrow-key driving (b3951af);
- guidance is **spoken on transitions only** (44e7bf8), and the board's
  dashboard buttons send `{"say":…}` lines the phone reads aloud;
- the BLE bridge pins the adapter alias to **"Distance Watch"** and
  retries forever (363bf09, 937f612).

`main` merged this branch wholesale, then added the camera scan on top.

## `qhackgps` — standalone compass navigation

An independent, still-runnable Android app (`com.example.qhackgps`) — the routing
prototype. Jetpack Compose map HUD, Google Directions walking routes, green-light
alignment with hysteresis, and guidance export over **Bluetooth Classic SPP** to
an Arduino:

```
QG,<dir>,<deltaDeg>,<distanceM>,<headingDeg>,<bearingDeg>,<aligned>,<obst>,<obstMM>
```

It is **not an ancestor of `v3`** — `git merge-base --is-ancestor` confirms no
shared lineage for the app code. `v3` reimplemented the useful ideas (path-first
steering, look-ahead bearing, cane-STOP haptics) in Kotlin under a different
package rather than merging this branch. It **is** an ancestor of `qhackfinal`,
and therefore of the app now on `main` — which still emits this exact wire line
at ~5 Hz, with `arduino/qhack_guidance_motor/` as its Arduino-side consumer.

Kept because it is where the merged app started, and because it documents the
ASCII/SPP transport that predates both the NUS cane link and the GATT protocol.

## `qhackgps-areamap` — persistent obstacle memory

Despite the name, this branch carries the **Shepherd app**
(`dev.quad.shepherd`) plus the mapping stack that
[`AREA_MAP_SCOPE.md`](AREA_MAP_SCOPE.md) plans against: a world-anchored
log-odds occupancy map (`AreaMap.kt`), ARCore pose, and A* planning over
remembered obstacles. Not merged into `main`.

## History

Kept for provenance. Each is a coherent snapshot, not a broken WIP.

| Branch | What it was |
|---|---|
| `v2` | Walkability segmentation + BEV traversability grid + polar planner — the first version of the current perception approach |
| `arduinov1` | Board bring-up: Modulino Distance → web dashboard, then Motors steering and Vibro haptics. Merged into `v3` under `board/` |
| `qhackcane` | Standalone distance-sensor board app with the BlueZ auto-pairing agent |
| `shepherd-snapdragon` | v1: detector + pinhole distance estimate + 9-column threat map. No depth model, no grid |
| `fastscnn-depthanything` | Model-selection spike — segmentation and depth candidates |

## Lineage

```
shepherd-snapdragon ──▶ v2 ──▶ v3   ◀── arduinov1 (merged as board/)
                               │    ◀── qhackcane (concepts)
                               │
                               ├── firmware ported (cd974fd) ──▶ qhackfinal
                               └── scan/ ported (selective) ───▶ main
qhackgps ──┬──▶ qhackfinal ──▶ main   (merged wholesale)
qhackcane ─┘
qhackgps-areamap ─────────────────────  Shepherd app + areamap; not merged
fastscnn-depthanything ───────────────  spike, not merged
```

The branch names carry an earlier project name. They're left alone on purpose —
rewriting published branch names would break every existing clone and reference
for no functional gain.

## A note on naming

On `v3` the Kotlin package is `dev.quad.shepherd` and the central service
class is `ShepherdService`; on `main` the app package is
`com.example.qhackgps`. Those are the real identifiers you need in order to
navigate each source tree, so the documentation cites them verbatim. The
project is called Lighthouse; the package renames are deferred as mechanical
changes that touch many files and carry build risk disproportionate to their
benefit right now.

Board and BLE identity is **not** legacy. These are live on-the-wire names
and must match the phone exactly — don't tidy them:

- **"Distance Watch"** and the Nordic UART Service
  (`6E400001-B5A3-F393-E0A9-E50E24DCCA9E`, with its RX/TX
  characteristics `…0002`/`…0003`) — the peripheral `main`'s app
  auto-discovers (`board/ble-bridge/`).
- **`QCane`, `QCane-Wheel`, the `bcf2f193-…` service** — the GATT/SPP
  identity of the `qcane_btd` host daemon, and what `v3`'s app scans for.

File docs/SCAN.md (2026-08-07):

# Lighthouse — Camera Obstacle Scan

The camera obstacle scan is `v3`'s **screen-thirds guidance**, ported into the
merged app on `main` as a toggleable feature. While it is on, the phone watches
the path through the back camera, decides each frame whether the middle of the
view is blocked, speaks every change of instruction ("Left" / "Right" / "Stop",
then "Straight" when the way clears), and steers the cane wheel with the same
words. While it is off — the default — the camera never opens and the app is
exactly the pre-scan qhackGPS.

Everything here is drawn from the code on `main`; constant names are the real
identifiers, so every number below can be grepped. The source is one package,
`app/src/main/java/com/example/qhackgps/scan/`; the feature's original,
full-stack incarnation is v3 commit `5d94090`.

The port is **detection-only by design** — v3 ran this same decision logic on
top of segmentation and depth models, and those stayed on their branch. What
that costs, honestly, is §4.

---

## 1. Pipeline

```
CameraX ImageAnalysis  (back camera, NO preview surface)
     │   KEEP_ONLY_LATEST, one "obstacle-scan" thread, ≥90 ms between frames (~10 Hz cap)
     ▼
rotate upright ─▶ letterbox into 640×640 ─▶ CHW float RGB 0..1
     ▼
YOLOv8 detector  (ONNX Runtime, QNN EP)        DetectionEngine + OrtSessions
     ▼
YoloPostProcessor                              conf ≥ 0.45, per-class NMS at IoU 0.5
     ▼
DistanceEstimator                              pinhole + closeness corrections
     ▼
ThirdsGuidance.update(obstacles, segClearance = null)
     ▼
Decision ∈ {STRAIGHT, LEFT, RIGHT, STOP}   ─▶  voice (§5), HUD (§6), wheel (§7)
```

`ObstacleScanner` is the glue, and two of its choices are deliberate:

- **The analysis use case binds alone.** No preview surface — which sidesteps
  the hidden-preview camera stall v3 had to fix, and means the map HUD never
  shows a camera feed.
- **`MIN_FRAME_INTERVAL_MS = 90`.** Running back-to-back on every camera frame
  pinned the GPU and thermal-throttled the SoC on v3. The thirds debounce
  assumes ~10 Hz and does not benefit from more; with `KEEP_ONLY_LATEST`, a
  slow (CPU-tier) detector degrades the scan rate, never the UI.

### Where inference runs

`OrtSessions` tries five tiers in order and labels the one that sticks:

| Tier | Backend | Strict | HUD label |
|---|---|---|---|
| 1 | QNN GPU (`libQnnGpu.so`, Adreno) | yes | `GPU` |
| 2 | QNN HTP (`libQnnHtp.so`, Hexagon NPU) | yes | `NPU` |
| 3 | QNN GPU, CPU fallback allowed | no | `GPU/CPU mixed` |
| 4 | QNN HTP, CPU fallback allowed | no | `NPU/CPU mixed` |
| 5 | plain CPU | — | `CPU` |

"Strict" sets `session.disable_cpu_ep_fallback`, so session creation **fails**
unless the entire graph compiled for the accelerator — without it, ONNX Runtime
silently runs everything on CPU and a session "created with QNN" proves
nothing. Only strict sessions earn the `GPU`/`NPU` labels. The SoC is spelled
out (`soc_model=69`, `htp_arch=79` — SM8750, Hexagon v79) because QNN's
auto-detection of the S25 Ultra's SM8750-AC variant is unproven. GPU-first is
kept from v3 (there it left the Hexagon free for the SLM; here it simply means
the scan never competes with anything for the NPU). The winning label shows in
the HUD chip (§6).

### Distances without a depth model

`DistanceEstimator` is the pinhole model over class-height priors:
`distance = realHeight × FOCAL_PX / boxHeightPx`, with `FOCAL_PX = 400` for
the 640-px letterboxed frame (S25 Ultra main camera, ~77° horizontal FOV) and
18 sidewalk-relevant priors (`person` 1.70 m … `cat` 0.30 m). Results clamp to
0.1–50 m; classes without a prior return no estimate.

Then the closeness corrections, because pinhole math *over*-estimates truncated
boxes exactly when the object is most dangerous:

- box touches **both** top and bottom edges → ≤ 1.0 m;
- box covers > 45 % of the frame → ≤ 1.1 m, whatever the class;
- unknown class but > 22 % of the frame → 2.2 m (a conservative number instead
  of none at all).

On v3 these estimates additionally calibrated a dense depth model. Here they
carry the whole job.

## 2. Decision semantics (`ThirdsGuidance`)

The frame splits into three vertical bands. Pure Kotlin, no Android types —
the ported JVM tests run on the desktop (`ThirdsGuidanceTest`, 16 tests).

- **An obstacle is a near detection**: estimated distance
  < `OBSTRUCT_DIST_M = 2.5` m — or, with no estimate, a box taller than
  `OBSTRUCT_HEIGHT_FRAC = 0.35` of the frame (big things in front of the lens
  are close). Far detections are ignored entirely.
- **Middle-third gate**: only near objects whose center falls in the middle
  third block forward. Objects in the outer thirds never block — they count
  against their side in the election instead.
- **Debounce**: a state change must persist `DEBOUNCE_FRAMES = 3` consecutive
  frames (~300 ms at ~10 Hz) both entering and leaving avoidance, so one noisy
  frame cannot start, end, or flip a dodge.
- **Side election**: each outer third scores
  `UNKNOWN_SIDE_SCORE (0.55) − OBJECT_PENALTY (0.35) × nearObjects`; the higher
  side wins, ties go RIGHT.
- **Latching**: the elected side holds while the middle stays blocked. It
  switches only if the latched side stops being viable
  (score < `SIDE_VIABLE_SCORE = 0.30`) while the other side is viable —
  debounced again.
- **STOP**: while blocked, neither side viable. Seg-less that means a near
  object on each side (0.55 − 0.35 = 0.20 < 0.30): blocked ahead, no clear
  side, halt.
- **Hysteresis**: `MIDDLE_BLOCK_ENTER = 0.45` / `MIDDLE_BLOCK_EXIT = 0.60`
  gate the segmentation walkable fraction. Dormant on `main` (the seg input is
  always null — see §4) but kept with the logic and its tests, so the seg feed
  could be reattached without touching the decision core.
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

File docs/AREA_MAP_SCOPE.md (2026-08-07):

# Scope: cane ToF → the areamap (never hit the same obstacle twice)

> **Status: historical scope document.** Written on `qhackfinal` before the
> merge to `main`, as the plan for feeding cane hits into the areamap. It is
> not what shipped: the merge brought `v3`'s screen-thirds camera scan
> instead ([`SCAN.md`](SCAN.md)), and none of the phases below are on
> `main`. The mapping stack this plugs into lives on the `qhackgps-areamap`
> branch ([`BRANCHES.md`](BRANCHES.md)). Kept because the observation model
> — weak arcs, evidence-only, no ray-clearing from a swinging beam — still
> holds if the work is picked back up.

Goal: every time the distance Modulino runs into an obstacle, that obstacle
gets remembered in a map, so later passes route around it instead of
rediscovering it by contact.
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

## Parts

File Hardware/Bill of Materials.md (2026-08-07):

# Bill of Materials

Total build cost: **~$196** excluding the phone and the 3D printer.

Every part below is in the built cane. All six printed assemblies have been
printed and fit-checked, the electronics are verified working, and the assembled
cane has been walked with.

For context on why this number matters: commercial smart canes run
$800–$1,150, AI wearables $2,000–$5,000, and a guide dog around $50,000 with a
multi-year waitlist. Most people with impaired vision live in low- and
middle-income countries where any of those exceeds an annual income. A cane you
can print and assemble for under $200 — reusing a phone the user already owns —
is the point of the project, not a side effect.

---

## Electronics — verified working in the built cane

| # | Part | Qty | Unit | Notes |
|---|---|---|---|---|
| 1 | **Arduino UNO Q** (Dragonwing QRB2210) | 1 | ~$54 | Quad-core Cortex-A53 + STM32 MCU + Adreno GPU, 4 GB RAM. Runs the cane app, the policy layer, and the Bluetooth daemon. |
| 2 | **Modulino Motors** | 1 | ~$12 | MAX22211 dual H-bridge, Qwiic, I²C `0x48`, ≤3.8 A per channel. Drives the steering wheel. |
| 3 | **Modulino Distance** | 1 | ~$11 | VL53L4CD time-of-flight. Near-field sensing at the cane tip. |
| 4 | **Modulino Vibro** | 1 | ~$9 | Local haptic alert. |
| 5 | **JGA25-370 geared DC motor, 12 V** | 1 | ~$14 | Standard JGA25 form factor with a 4 mm D-shaft. Drives the omni wheel. |
| 6 | **Qwiic / JST-SH 4-pin cables** | 3 | ~$2 ea | Daisy-chain. Bus order is irrelevant — each node has its own address. |
| 7 | **Anker 737 Power Bank** (24 000 mAh, 140 W) | 1 | ~$100 | Powers everything and charges the phone. A dedicated mount is included in the CAD. |
| 8 | **USB-C PD trigger board, 12 V** | 1 | ~$8 | Negotiates 12 V PD from the Anker for the motor's `VM` terminals. |
| 9 | **Hook-up wire, heat-shrink, JST pigtails** | — | ~$5 | Motor leads and power distribution. |

**Electronics subtotal: ~$219** at single-unit retail, or **~$115 without the
power bank** if you already own a USB-C PD bank — any 12 V-capable PD source
works, the mount is just sized for the 737.

### Phone

Developed on a **Galaxy S25 Ultra** (Snapdragon 8 Elite). Not counted in the
total — the design assumes the user already has a phone, which is the reason
this build has no LiDAR line item. Any Snapdragon 8-series device with an NPU
should work; QNN degrades gracefully if the config doesn't match.

---

## 3D-printed parts — printed and fitted

All models are in [`CAD/`](CAD/) as STL, with renders. The editable source is a
live Onshape document — [open it here](https://cad.onshape.com/documents/c0b905e8d1b94a52d9e9ca97/w/f6521fb190a4be4abaa604ca/e/e523a5a009f76747b4bb6591)
— and the committed STLs are exports of it. Six printed assemblies:

| # | Part | STL | Purpose |
|---|---|---|---|
| 10 | **Omni wheel** (print-in-place) | `Omni Wheel.stl` | Six-roller omni wheel. Rollers print already captured in the hub — no assembly, no bearings, no separate axles. |
| 11 | **Main frame** | `Main.stl` | Lower assembly: carries the motor, wheel, and Distance module at the cane tip. |
| 12 | **Hub mount + cover** | `Hub Mount - Hub Cover.stl` | Clamps the assembly to the cane shaft. |
| 13 | **Electronics housing + cover** | `Mount & Electronics - Electronics Cover.stl` | Skeletonized enclosure for the UNO Q and Modulinos. |
| 14 | **Distance sensor mount** | `Mount & Electronics - Distance Mount.stl` | Aims the ToF sensor forward and down toward the tip's path. |
| 15 | **Phone mount** | `S25 Ultra - Phone Mount.stl` | S25 Ultra cradle on a pivoting hinge; holds the rear cameras facing forward. |
| 16 | **Battery mount** | `Anker 737 Power Bank - Battery Mount.stl` | Anker 737 cradle with the ports left accessible. |

**Filament cost: ~$12–18** for the full set in PLA or PETG (roughly 400–550 g
depending on infill). At a print-service rate, budget $60–90 instead.

> **Print status.** All parts have been **printed and fit-checked** on the built
> cane. Note that roller clearance on the print-in-place wheel is
> printer-dependent — if your rollers come off the bed fused and won't work free,
> scale clearance up 0.05 mm and reprint.

### Omni wheel provenance

The wheel is based on the open-source print-in-place omni wheel published on
GrabCAD: <https://grabcad.com/library/omni-wheel-print-in-place-1> — adapted here
for the JGA25's 4 mm D-shaft and this cane's tip geometry.

The print-in-place approach is deliberate and it is what makes the cost figure
real. A commercial omni wheel is $15–25 plus a hub adapter, and the reference
research design used a machined wheel-to-hub adapter. Printing the rollers
captive removes the wheel, the adapter, the bearings, and the assembly step in
one move. Verify the license terms on the GrabCAD page before redistributing the
derived geometry.

## Fasteners and shaft

| # | Part | Qty | Unit | Notes |
|---|---|---|---|---|
| 17 | **White cane shaft or 1.25 in PVC** | 1 | ~$10–20 | Cut to user height. A real white cane is preferable — the familiar object is part of why users trust the device. |
| 18 | M3 / M4 bolts, assorted | ~20 | ~$6 | Frame, covers, clamps. |
| 19 | M3 / M4 heat-set inserts | ~12 | ~$5 | Press into the printed parts. |
| 20 | VHB tape | — | ~$4 | Securing the PD trigger board. |

**Fasteners subtotal: ~$25–35**

---

## Cost summary

| Category | Cost |
|---|---|
| Electronics, excluding power bank | ~$115 |
| Anker 737 power bank | ~$100 |
| 3D-printed parts (filament) | ~$15 |
| Shaft and fasteners | ~$30 |
| **Total, with a new power bank** | **~$260** |
| **Total, reusing a USB-C PD bank you own** | **~$160** |
| **Sensing hardware avoided (LiDAR)** | **$0 — the phone camera and NPU replace it** |

Call it **~$196 typical**, and note what dominates: the power bank and the UNO Q.
The perception stack — the part doing metric depth, semantic segmentation, and
object detection — costs nothing beyond a phone the user already carries. That is
the direct consequence of running everything on the Snapdragon NPU instead of
bolting on a laser scanner.

For comparison, the published research design this steering approach builds on
came to roughly $400, with a 2D LiDAR as the single largest line item.

---

## Motor wiring — read before powering up

The wheel motor sits across screw terminals **`1A` + `2A`**. That is one
half-bridge from channel A and one from channel B — *not* a single channel's own
pair. So the sketch drives the two channels in **opposite phase**:

```cpp
motors.setDcSpeedRaw(+raw, -raw);   // one direction
motors.setDcSpeedRaw(-raw, +raw);   // the other
```

Both channels draw current while it spins. This also works unchanged if the motor
is moved to a single channel's pair (`1A`/`1B`), so it is a safe default either
way. If left and right come out reversed, flip the sign in `driveMotor()`.

> **The trap that will cost you an hour.** The Qwiic cable carries **3.3 V logic
> only**. The JGA25 needs **12 V on the `VM` + `GND` screw terminals** from the PD
> trigger board. Without it, the H-bridge accepts every command, reports success
> at every layer, and drives nothing. The yellow `VM` LED is your confirmation.

Measure which terminals actually drive:

```bash
python3 host/qcane_btd.py --selftest        # 40% duty
python3 host/qcane_btd.py --selftest 100    # full power
```

Only a channel with the motor across it draws current. Readings of 0.6–1.3 mA are
the ADC noise floor — nothing is being driven. If every row looks like that while
`mode` still reads `dc`, check the 12 V supply first, then the lead clamping.

---

## What this build does *not* need

- **No LiDAR, no depth camera, no stereo rig.** Metric depth is inferred from a
  single RGB camera on the Hexagon NPU. This is the largest cost and complexity
  reduction in the design.
- **No separate BLE module.** The UNO Q's own radio serves both GATT and SPP.
- **No commercial omni wheel or machined hub adapter.** Both are printed as one
  part.
- **No cloud service** for obstacle avoidance or steering. Street routing is
  optional; everything safety-relevant runs offline.
- **No custom PCB.** Three Modulinos on a Qwiic chain.

## Accessibility notes

Choices made for the user rather than the demo:

- **It stays a white cane.** The familiar form is retained deliberately —
  contact sensing still works if every electronic system fails, and the research
  literature attributes part of the measured confidence gain to keeping the
  white cane as the base.
- **Steering, not beeping.** Feedback is a physical nudge, leaving hearing free.
  Audio is available but never required for obstacle avoidance.
- **Nothing to configure to walk.** Power the board and go; routing is optional.
- **Everything is printable and documented.** No proprietary parts, no vendor
  lock-in, no service contract. If a part breaks, print another.

## Next steps

The cane is built and walked with. What remains is measurement and evaluation:

1. Measure end-to-end steering latency on the assembled cane — obstacle entering
   frame to wheel torque. Mechanical inertia is not captured by the bench numbers
   in [`../docs/PERFORMANCE.md`](../docs/PERFORMANCE.md).
2. Characterize battery life under sustained motor load, with the phone charging
   from the same bank.
3. Weigh the assembly and assess hand fatigue over a long walk. Nothing in this
   BOM accounts for that, and it is the kind of thing that only shows up past the
   thirty-minute mark.
4. Evaluate with users with impaired vision. Every other test is a proxy for this
   one.

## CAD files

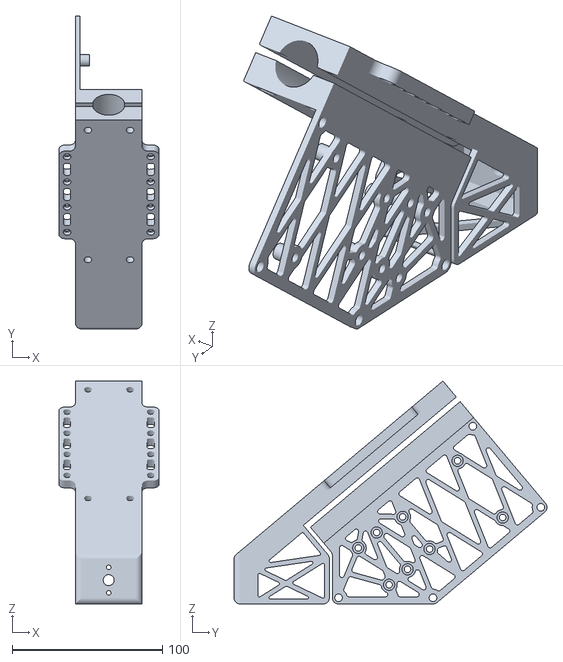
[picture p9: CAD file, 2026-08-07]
Hardware/CAD/Main.stl
66.9 x 208.5 x 148.5

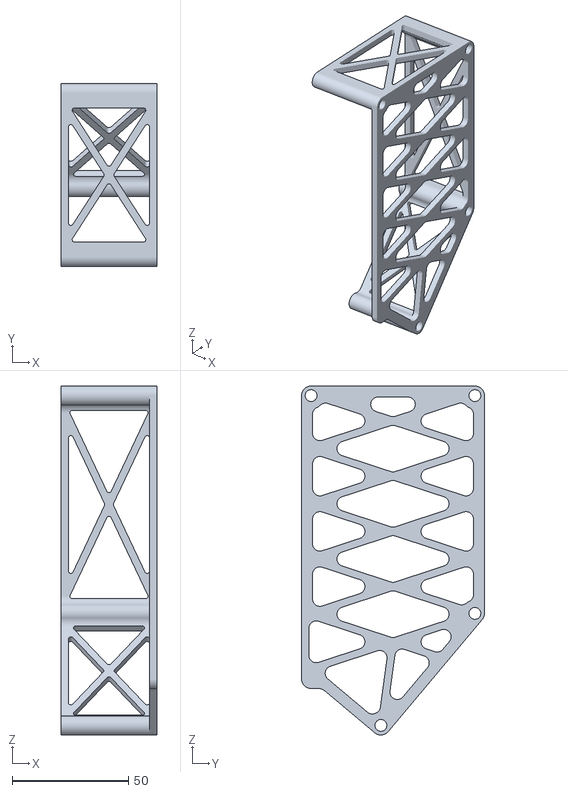
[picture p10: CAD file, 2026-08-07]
Hardware/CAD/Mount & Electronics - Electronics Cover.stl
41.3 x 78.7 x 150.2

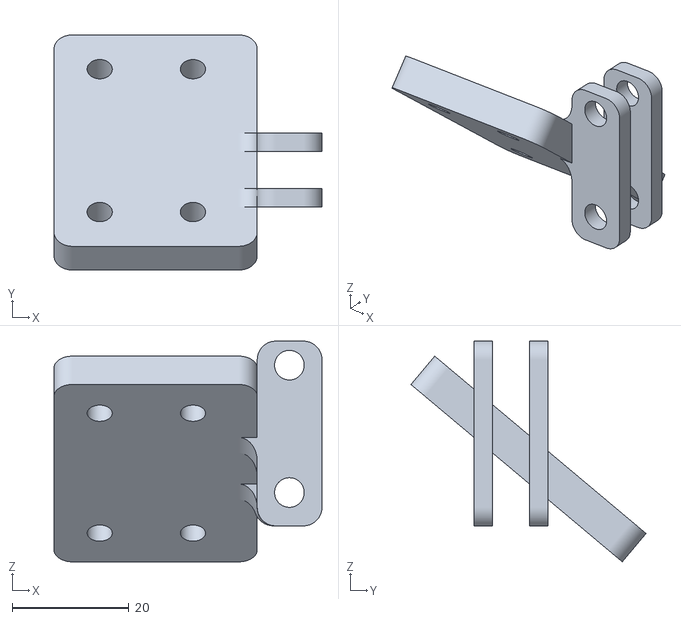
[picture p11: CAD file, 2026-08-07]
Hardware/CAD/Mount & Electronics - Distance Mount.stl
46.0 x 40.4 x 37.9

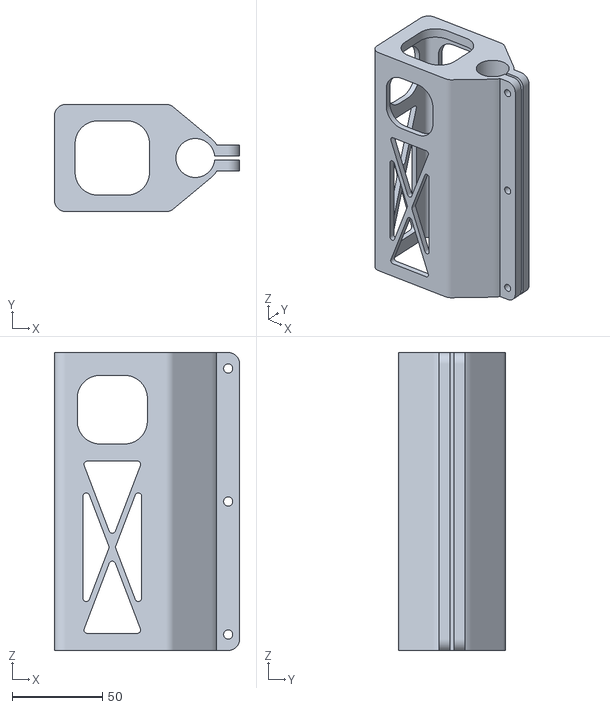
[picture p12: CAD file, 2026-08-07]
Hardware/CAD/Anker 737 Power Bank - Battery Mount.stl
102.9 x 59.5 x 165.5

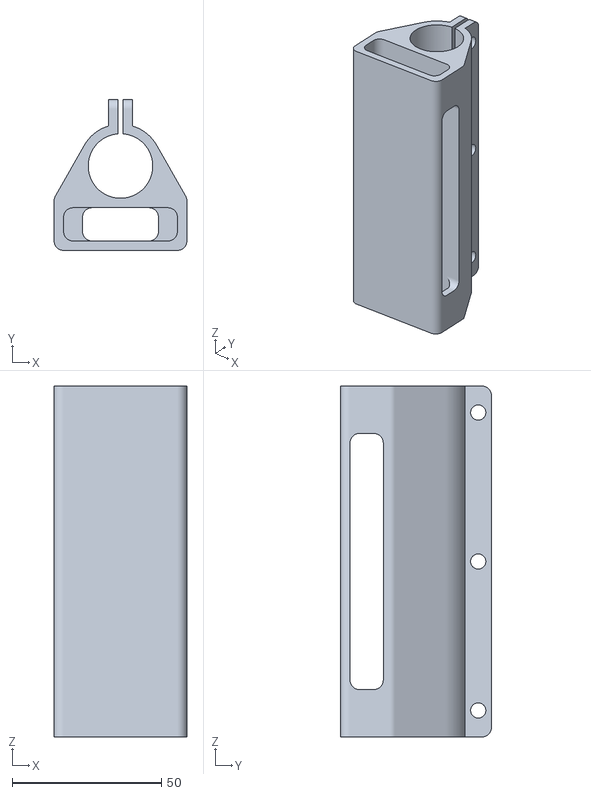
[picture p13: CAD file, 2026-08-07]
Hardware/CAD/Hub Mount - Hub Cover.stl
44.5 x 50.5 x 117.5

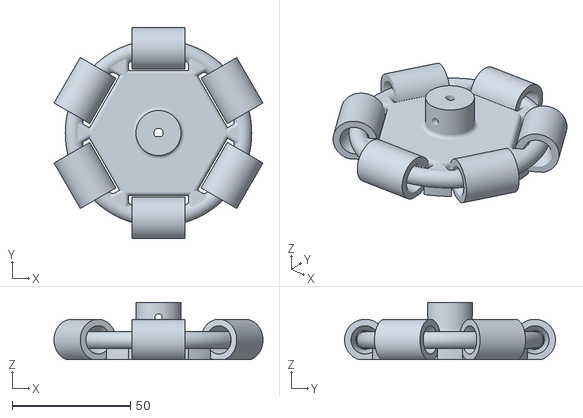
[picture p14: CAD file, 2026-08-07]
Hardware/CAD/Omni Wheel.stl
88.5 x 89.3 x 24.2

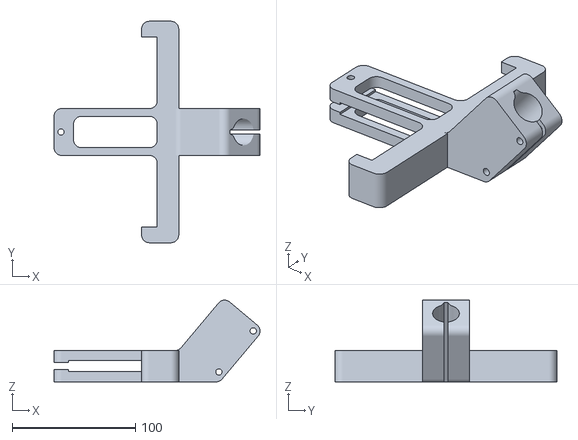
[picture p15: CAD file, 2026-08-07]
Hardware/CAD/S25 Ultra - Phone Mount.stl
167.1 x 179.7 x 66.3

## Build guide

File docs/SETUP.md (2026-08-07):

# Setup from scratch

Assumes nothing installed. Two independent halves — the phone app and the cane
board — and the phone app is useful on its own, so start there.

## What you need

| | Requirement | Notes |
|---|---|---|
| Phone | Snapdragon 8 Elite Android device | Developed and tested on **Galaxy S25 Ultra**, Android 15. `minSdk 31`. Other Snapdragon devices should work; QNN falls back gracefully if the NPU config doesn't match. |
| Dev machine | Android Studio Ladybug or newer | x86-64 Linux/macOS/Windows. See the note on Windows-on-ARM below. |
| Board *(optional)* | Arduino UNO Q + 3 Modulinos | Without it you get on-screen guidance and speech but no physical steering. |
| Keys *(optional)* | Google Maps API key | Only for outdoor street routing. Without it, navigation uses straight-line compass bearing. |

The app runs **without the board** and **without an API key**. Both degrade
features, neither blocks the build.

---

## 1 — Clone and pick the branch

```bash
git clone https://github.com/<your-account>/lighthouse.git
cd lighthouse
git checkout v3          # the full perception system this guide describes
```

This guide sets up **`v3`** (`dev.quad.shepherd`, `board/qcane-wheel/`).
`main` carries the merged demo system instead — the qhackGPS app with the
camera scan, plus the `board/distance-watch/` firmware; for that, stay on
`main` and see [`SCAN.md`](SCAN.md) and [`BRANCHES.md`](BRANCHES.md).

## 2 — Android SDK

Install Android Studio, then in **SDK Manager** confirm:

- Android SDK Platform **35**
- Android SDK Build-Tools 35.x
- Android SDK Platform-Tools (gives you `adb`)

Put `adb` on your `PATH` — you'll need it to push models.

```bash
adb devices     # should list your phone as `device`, not `unauthorized`
```

To get there: on the phone, **Settings → About phone → tap Build number 7×**,
then **Developer options → USB debugging**. Accept the dialog when you plug in.

## 3 — Configure `local.properties`

Gradle writes the SDK path here on first sync. Add your Maps key if you want
outdoor routing:

```properties
sdk.dir=/path/to/Android/Sdk
maps.apiKey=AIza...
```

Get a key from the [Google Cloud Console](https://console.cloud.google.com/) and
enable **Maps SDK for Android**, **Routes API**, **Geocoding API**, and
**Places API (New)**.

`local.properties` is gitignored — never commit it.

> Without `maps.apiKey`, `RoutesClient.available` is false. Navigation still
> works: it falls back to a straight-line bearing to the destination, which is
> also exactly what indoor mode does by design.

## 4 — Build and test

```bash
./gradlew :app:testDebugUnitTest     # 10 test classes, no device needed
./gradlew :app:assembleDebug
./gradlew :app:installDebug          # or hit Run in Android Studio
```

Run the tests first — they cover the pure-Kotlin math (planner mode machine,
grid, command aggregation, depth calibration, YOLO post-processing, nav) and need
no hardware, so a green run confirms your toolchain before any device enters the
picture.

## 5 — Install the models

**This step is required for full function.** Only the YOLOv8n detector is
committed; depth and segmentation weights are not, for size and licensing
reasons. Complete instructions per model: [`MODELS.md`](MODELS.md).

The short version — export depth, then push everything:

```bash
# Depth (Apache-2.0). Needs Linux/WSL + torch; see MODELS.md.
./scripts/export_depth_model.sh 294

adb push depth_anything_v2_small.onnx \
  /sdcard/Android/data/dev.quad.shepherd/files/models/
```

> **Use the Metric checkpoints.** Depth-Anything-V2-**Metric** outputs distance
> in meters directly. The relative-depth checkpoints do not, and the grid,
> calibrator, and every meter threshold in the planner assume meters — swapping
> one in fails quietly rather than loudly. `MODELS.md` covers this.

The app starts without these and says so on screen. Steering quality depends on
them, so don't judge the system before they're installed.

## 6 — Grant permissions and go

On first launch, allow **Camera**, **Location**, **Microphone**, **Nearby
devices**, and **Notifications**. The guidance pipeline runs as a foreground
service so it survives the screen turning off — which is the normal way to use
it, phone mounted and in motion.

Sanity check: the status bar should read **`Hexagon NPU (QNN)`** or a GPU
provider. If it reads `CPU`, QNN failed to load — check Logcat for tag
`DetectionEngine` or `OrtSessions`.

---

## 7 — Cane board (optional)

Full detail: [`BOARD.md`](BOARD.md) and
[`../Hardware/Assembly Instructions.md`](../Hardware/Assembly%20Instructions.md).

```bash
# On the UNO Q
arduino-app-cli app start ~/lighthouse/board/qcane-wheel
arduino-app-cli app logs  ~/lighthouse/board/qcane-wheel --follow
```

Open `http://<board-ip>:7000` for the dashboard. Then install the host-side
Bluetooth daemon as a user service:

```bash
mkdir -p ~/.config/systemd/user
cp ~/lighthouse/board/qcane-wheel/host/qcane-btd.service ~/.config/systemd/user/
systemctl --user daemon-reload
systemctl --user enable --now qcane-btd
loginctl enable-linger arduino
```

Verify the whole chain before involving the phone:

```bash
cd ~/lighthouse/board/qcane-wheel
python3 host/qcane_btd.py --send left --speed 5    # wheel should spin
```

The phone then finds the board by GATT service UUID within seconds. No pairing.

---

## Platform notes

**Windows on ARM.** The AI Hub cloud export chain doesn't install — no ARM64
wheels for `opencv-python` or `torch`. Export models in WSL Ubuntu instead, or on
an x86-64 machine, then `adb push`. Building and running the app itself is fine.

**QNN native libraries.** `useLegacyPackaging = true` in `app/build.gradle.kts`
is load-bearing, not vestigial: GenieX `dlopen`s its plugins by absolute path
from `nativeLibraryDir`, and without legacy packaging the `.so` files stay
compressed inside the APK and that path is empty. You get `Invalid plugin` at
runtime. Don't "clean this up."

**The manifest declares `libcdsprpc.so` and `libOpenCL.so`** via
`<uses-native-library>`. Since API 31 the linker blocks undeclared vendor
libraries — these are FastRPC to the Hexagon DSP and the Adreno OpenCL backend.
Removing them silently drops you to CPU.

---

## Troubleshooting

| Symptom | Cause / fix |
|---|---|
| Status bar reads `CPU` | QNN didn't load. Check Logcat `OrtSessions`. Confirm the manifest still declares the two vendor libraries. |
| `Invalid plugin` on startup | `useLegacyPackaging` got turned off. Restore it. |
| Guidance seems oblivious to obstacles | Depth model missing — see step 5. Check the on-screen model status. |
| Everything reads as an obstacle | Camera pitch. The ground latch self-calibrates but can't recover from a camera aimed at the sky or the floor. Remount level and forward. |
| Wheel never moves | `VM` supply. The Qwiic cable is 3.3 V logic only; the motor needs its own 5 V on the screw terminals. Yellow `VM` LED confirms. Then `--selftest`. |
| Wheel brakes on a clear path | Known bug — see [`KNOWN_ISSUES.md`](KNOWN_ISSUES.md), the `S` letter collision. |
| Board reports distance, phone ignores it | Known bug — see [`KNOWN_ISSUES.md`](KNOWN_ISSUES.md), telemetry channel mismatch. |
| No routes, "navigation unavailable" | `maps.apiKey` missing or the Routes API isn't enabled on that key. |
| Speech is robotic | Neural voice hasn't downloaded yet — needs unmetered Wi-Fi on first launch. System TTS is the fallback. |

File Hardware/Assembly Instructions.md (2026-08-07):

# Assembly Instructions

Three stages, all of which have been carried through on the built cane. **Stage 1
(electronics) is verified working** and needs no mechanical assembly at all — do
it first on a desk, before you print anything. Stages 2 and 3 print and assemble
the cane. The completed cane has been walked with.

Parts and costs: [`Bill of Materials.md`](Bill%20of%20Materials.md)

Full assembly

*Complete assembly — phone mount at the top, battery and electronics housings
mid-shaft, drive assembly with the omni wheel at the tip.*

---

## Stage 1 — Electronics bring-up (verified)

Complete this entire stage with the parts loose on a desk before committing to a
print. If the wheel spins from a phone command here, the hard part is done.

### 1.1 Chain the Modulinos

```
UNO Q ──▶ Modulino Motors ──▶ Modulino Vibro ──▶ Modulino Distance
```

Order doesn't matter on I²C — each node answers on its own address. On the UNO Q
the Qwiic connector is `Wire1`.

### 1.2 Power the motor from 12 V

Set the USB-C PD trigger board to **12 V**, feed it from the power bank, and wire
its output to the Modulino Motors **`VM` + `GND`** screw terminals.

> The Qwiic cable is **3.3 V logic only**. Skip this and the H-bridge will accept
> every command and drive nothing — a confusing failure, because every software
> layer reports success. The yellow `VM` LED confirms power.

### 1.3 Wire the JGA25 across `1A` + `2A`

See the [wiring note in the BOM](Bill%20of%20Materials.md#motor-wiring--read-before-powering-up).
`1A` and `2A` are one half-bridge from each channel, which is why the sketch
drives them in opposite phase.

### 1.4 Flash and start the board app

```bash
arduino-app-cli app start ~/lighthouse/board/qcane-wheel
arduino-app-cli app logs  ~/lighthouse/board/qcane-wheel --follow
```

Open `http://<board-ip>:7000` — the QCane Link dashboard. You should see live
distance readings, motor telemetry with current and voltage graphs, and vibro
state.

### 1.5 Verify the full chain without a phone

The Bluetooth daemon can inject commands into itself, exercising everything down
to the MCU and waiting for the sketch's acknowledgement:

```bash
cd ~/lighthouse/board/qcane-wheel
python3 host/qcane_btd.py --send left --speed 5
python3 host/qcane_btd.py --send right
python3 host/qcane_btd.py --send stop
python3 host/qcane_btd.py --watch       # live command + state view
python3 host/qcane_btd.py --selftest    # profile the motor wiring
```

`--send` prints `left (speed 5) acknowledged by the app` **only after the MCU
reports back**, so success there means the whole path worked.

### 1.6 Install the Bluetooth daemon as a service

```bash
mkdir -p ~/.config/systemd/user
cp ~/lighthouse/board/qcane-wheel/host/qcane-btd.service ~/.config/systemd/user/
systemctl --user daemon-reload
systemctl --user enable --now qcane-btd
loginctl enable-linger arduino     # survives logout, starts at boot
```

The unit must point at the **same app folder the app runs from** — the Unix socket
lives in that folder's `.run/`.

Why the daemon runs on the host rather than in the app: the app's Python executes
in a container with no `/run/dbus` mount, where `AF_BLUETOOTH` fails outright. It
cannot reach BlueZ at all. So the radio is driven host-side and the two halves
meet on a Unix socket inside the app folder, which is already bind-mounted in. A
useful side effect: a connected phone survives `arduino-app-cli app restart`
while you iterate.

### 1.7 Connect the phone

Install the app ([`../docs/SETUP.md`](../docs/SETUP.md)) and power the board. The
phone scans by **GATT service UUID**, not by name, and connects within seconds. No
pairing needed.

Protocol reference: [`../docs/BOARD.md`](../docs/BOARD.md)

---

## Stage 2 — Print the parts

All STLs are in [`CAD/`](CAD/). Six assemblies, ~400–550 g of filament total.
The editable source is a live Onshape document —
[open it here](https://cad.onshape.com/documents/c0b905e8d1b94a52d9e9ca97/w/f6521fb190a4be4abaa604ca/e/e523a5a009f76747b4bb6591)
— if you need to change a dimension before printing.

| Part | File | Notes |
|---|---|---|
| Omni wheel | `Omni Wheel.stl` | **Print-in-place** — see below |
| Main frame | `Main.stl` | Largest part; carries motor, wheel, ToF |
| Hub mount + cover | `Hub Mount - Hub Cover.stl` | Shaft clamp |
| Electronics housing + cover | `Mount & Electronics - Electronics Cover.stl` | Skeletonized |
| Distance mount | `Mount & Electronics - Distance Mount.stl` | ToF aiming bracket |
| Phone mount | `S25 Ultra - Phone Mount.stl` | Sized for S25 Ultra |
| Battery mount | `Anker 737 Power Bank - Battery Mount.stl` | Sized for Anker 737 |

**Suggested settings.** PETG preferred for the structural parts (frame, hub
mount, phone mount) — it survives being dropped and flexed better than PLA, and a
cane gets both. PLA is fine for the covers. 0.2 mm layers, 4 perimeters, 25–30%
infill on structural parts.

> **These parts have been printed and fit-checked** on the built cane. The one
> thing to watch is the print-in-place wheel: roller clearance is
> printer-dependent, so if yours come off the bed fused, work them free by hand
> or scale clearance up 0.05 mm and reprint.

### The print-in-place omni wheel

Omni wheel

*Six-roller print-in-place omni wheel, rollers captive in the hub.*

Based on the open-source design at
<https://grabcad.com/library/omni-wheel-print-in-place-1>, adapted for the JGA25's
4 mm D-shaft.

The rollers print **already captured** in the hub — no bearings, no axles, no
assembly. That removes a commercial omni wheel ($15–25), a machined hub adapter,
and an assembly step from the build.

Print it **flat, no supports, and slow** — 30–40 mm/s. The roller clearances are
the tightest tolerance in the whole project and they are printer-dependent. When
it comes off the bed, the rollers will be fused; work each one free by hand until
all six spin. If they won't free up, scale roller clearance up by 0.05 mm and
reprint. Getting this part right is what makes the steering feel like a nudge
rather than a drag, so it's worth a second attempt.

Check the license terms on the GrabCAD page before redistributing derived
geometry.

---

## Stage 3 — Assemble

### 3.1 Drive assembly at the tip

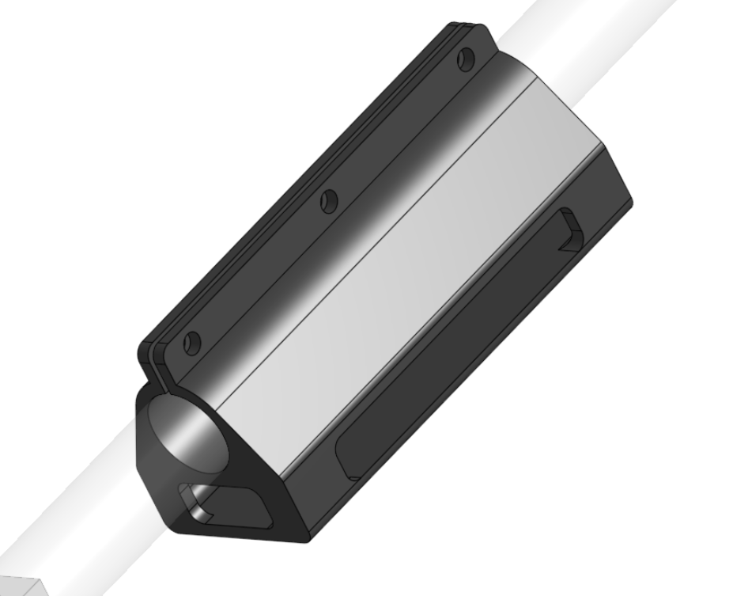
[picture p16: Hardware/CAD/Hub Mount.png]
Hub mount


Mount the JGA25 in the main frame, press the omni wheel onto the 4 mm D-shaft,
and clamp the frame to the bottom of the shaft with the hub mount and cover.

Orient the wheel so its **roll axis is fore-aft**. That is the entire principle:
the wheel resists *lateral* motion — the force the user feels as steering — while
rolling freely forward, so the cane never drags.

This joint takes the full steering reaction torque. It is the most likely thing to
work loose in field testing; check it before every session.

### 3.2 Distance sensor

Fit the Modulino Distance into its bracket on the main frame, aimed **forward and
slightly down**, toward where the tip is about to be. This catches what the phone
camera cannot see — low obstacles inside the camera's near blind spot.

### 3.3 Electronics housing

Electronics mount

*Skeletonized housing with the UNO Q and Modulino stack.*

Seat the UNO Q and the Modulino chain in the housing and close the cover. Route
the Qwiic chain so no cable crosses a clamp face. The skeletonization is for
airflow as much as weight — the UNO Q runs warm under sustained load.

### 3.4 Battery

Battery mount

Clip the Anker 737 into its cradle mid-shaft. Ports stay accessible so you can
charge without disassembly, and so the phone can charge from the same bank on a
long walk.

Mount it **opposite the electronics housing** if you can, to balance the shaft.
An unbalanced cane is tiring in a way that doesn't show up in a ten-minute test.

### 3.5 Phone mount

Phone mount

*S25 Ultra cradle on a pivoting hinge — rear cameras face forward.*

Clamp the mount high on the shaft and seat the phone with the **rear cameras
facing forward** along the direction of travel, roughly chest height. Use the
hinge to set pitch, then tighten.

The perception stack tolerates a fair amount of mounting slop: the grid
self-calibrates camera height from a 12th-percentile ground estimate and reads
pitch and roll live from the gravity sensor. What it cannot recover from is a
camera seeing mostly sky or mostly ground, or a mount loose enough to let the
phone swing — the ground latch will chase the motion. Watch `ground=` in the
telemetry; it should settle near 0.

### 3.6 Power-up order

1. Power bank on, PD trigger board showing 12 V
2. UNO Q boots, board app starts (dashboard reachable)
3. Launch the phone app, confirm the cane link connects
4. `--send left` or the dashboard buttons to confirm the wheel drives
5. Walk

---

## Field-test protocol

**Always test with a sighted companion.** Suggested progression:

1. **Static** — obstacle 1.5 m ahead. The wheel should pick a side and commit,
   not oscillate.
2. **Corridor** — walk a clear hallway. Near-neutral. If it hunts, check camera
   pitch and the ground latch.
3. **Single obstacle** — a box on a clear sidewalk. Expect a smooth deviation and
   a return to the original heading. Transitions log as `deviate` / `return`.
4. **Off-path obstacle** — place one *beside* the route. Steering should ignore it
   completely; that's the path-first planner working.
5. **Dead end** — walk at a wall. Expect **STOP** (`X`), not a guess.
6. **Route following** — set an outdoor destination and confirm the wheel biases
   toward the route.

Live telemetry:

```bash
adb logcat -s ShepherdTime
```

Reproducible latency measurement: [`../docs/PERFORMANCE.md`](../docs/PERFORMANCE.md)

Known defects, including two that affect behavior:
[`../docs/KNOWN_ISSUES.md`](../docs/KNOWN_ISSUES.md)

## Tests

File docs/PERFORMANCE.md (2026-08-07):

# Performance

Two kinds of number appear here, and they are kept strictly separate:

- **Measured** — captured from hardware, with the command to reproduce it.
- **Design budget** — a target the code enforces (a cadence, a timeout). Real,
  but not a measurement of achieved latency.

Nothing below is extrapolated or estimated. Where we don't have a number, it says
so.

---

## Reproducing the phone-side measurement

The pipeline instruments itself. Every 5th frame with depth,
`FrameAnalyzer` emits a full per-stage breakdown under tag `ShepherdTime`:

```bash
adb logcat -s ShepherdTime
```

Format (`FrameAnalyzer.kt:318-332`):

```
mode=in yolo=45ms(1Hz) depth=32ms ffnet=2ms ade=180ms(async)
grid=8ms plan=1ms e2e=98ms ground=0.05m scale=1.05 steer=-15°
```

| Field | Meaning |
|---|---|
| `mode` | `in` / `out` — which domain-matched model pair is active |
| `yolo` | Detector inference; runs at 1 Hz, off the steering path |
| `depth` | Metric depth inference |
| `ffnet` / `ade` | Walkability segmentation — outdoor inline / indoor async |
| `grid` | Ground projection + log-odds update + ground self-calibration |
| `plan` | 37-sector raycast and planner decision |
| `e2e` | Whole frame, camera callback to guidance verdict |
| `ground` | Self-calibrated ground offset — should settle near 0 |
| `scale` | Depth-scale correction from the calibrator — should sit near 1.0 |
| `steer` | Chosen corridor angle |

Two of these are diagnostics as much as timings. If `ground` drifts far from 0,
the camera mount pitch is wrong. If `scale` sits far from 1.0, monocular depth is
being systematically corrected — check that a Metric checkpoint is installed and
not a relative one.

To compare accelerators, watch the provider that `OrtSessions` reports at
startup, then force the CPU tier and re-measure the same scene.

> **Provenance note.** The design budgets below are read from source. Populate
> the measured table by running the command above on your device — we are not
> quoting phone latency figures we can't attach a capture to.

### Phone: design budgets (from source)

| Stage | Budget | Constant |
|---|---|---|
| Analysis cadence | 90 ms (~11 Hz) | `MIN_FRAME_INTERVAL_MS` |
| Depth inference gate | 300 ms (~3 Hz) | `DEPTH_INTERVAL_MS` |
| Detection gate | 1000 ms (1 Hz) | `DETECT_INTERVAL_MS` |
| Motor decision window | 200 ms (5 Hz) | `CommandAggregator.PERIOD_MS` |

### Phone: measured

| Stage | Median | p95 | Device |
|---|---|---|---|
| _run `adb logcat -s ShepherdTime` and fill in_ | | | |

---

## Measured: on-board depth, UNO Q (CPU only)

This one we do have. It's the experiment that decided where depth runs.

**Setup:** UNO Q / QRB2210, 4× Cortex-A53 @ 2 GHz, **CPU only**, 3 threads,
12 iterations, synthetic input. Reproduce with `board/depth-spike/bench.py` on
the `v3` branch.

| Model | Input | Median | p95 | FPS | Peak MB | File MB |
|---|---|---|---|---|---|---|
| MiDaS float | 256×256 | 864 ms | 1023 ms | 1.16 | 197 | 0.1 |
| MiDaS w8a8 | 256×256 | 1001 ms | 1009 ms | 1.00 | 157 | 0.3 |
| Depth-Anything-V2-Small | 126×126 | 452 ms | 453 ms | 2.21 | 213 | 99.1 |
| Depth-Anything-V2-Small | 252×252 | 1728 ms | 1732 ms | 0.58 | 244 | 99.1 |
| Depth-Anything-V2-Small | 378×378 | 4172 ms | 4184 ms | 0.24 | 303 | 99.1 |

**What this settled.** Depth on the board's CPU is not viable for steering. Even
the fastest configuration — DA-Small at a degraded 126×126 — is 452 ms per frame,
and resolution scales brutally: 252×252 costs 3.8× more than 126×126, and
378×378 costs 9.2×. A steering loop needs depth at a few Hz with the *pixels* to
locate a corridor, and this table offers a choice between too slow and too
coarse.

Note also that int8 quantization made MiDaS **slower** (1001 ms vs 864 ms) — on
a CPU-only A53 with no NPU to consume the quantized graph, w8a8 buys smaller
weights and pays in dequantization. Quantization is not automatically a win; it's
a win when there's an accelerator that wants it.

Hence the split the system actually uses: **depth and segmentation on the phone's
NPU/GPU, the board does actuation and near-field sensing.** The board's
Dragonwing has an Adreno GPU, so a QNN path there is future work rather than a
dead end — but the phone's Hexagon is the right target today.

---

## Design budgets: safety timeouts

Every one of these is enforced in code. See
[`ARCHITECTURE.md`](ARCHITECTURE.md) for the mechanisms.

| Guard | Threshold | Where |
|---|---|---|
| Board motor failsafe — command stream silent | 2000 ms | `COMMAND_TIMEOUT_MS`, `sketch.ino` |
| Phone STOP after empty decision windows | 3 windows (600 ms) | `CommandAggregator` |
| BLE write-stall teardown | 4000 ms | `WRITE_STALL_MS`, `CaneBleLink` |
| BLE consecutive write failures | 8 | `WRITE_FAIL_STREAK` |
| BLE watchdog tick | 3000 ms | `CaneBleLink` |
| Haptic STOP repeat interval | 1200 ms | `HapticFeedback` |
| Route look-ahead | 12 m | `LOOKAHEAD_M`, `RouteTracker` |
| Off-route reroute | 30 m × 4 fixes | `OFF_ROUTE_M`, `OFF_ROUTE_STRIKES` |

---

## Measured: companion SLM

From `GenieBench` on Galaxy S25 Ultra (Snapdragon 8 Elite), Qwen3.5-2B Q4_0 on
Hexagon NPU:

| Metric | Value |
|---|---|
| First token | 186 ms |
| Decode | 12.1 tok/s |

Reply length is capped at `MAX_REPLY_TOKENS = 96` (~8 s of speech at that rate)
and history at 6 messages, to bound both rambling and prefill cost.

This is **off by default** (`COMPANION_ENABLED = false`) — it is a conversational
feature, not part of steering, and it wants the same Hexagon the vision models
would otherwise use. That contention is exactly why vision prefers the Adreno GPU
first.

---

## Deeper profiling with QUAD

For per-op HTP cycle counts, power, and CPU/GPU/NPU allocation comparisons, the
QUAD MCP server profiles on real silicon over ADB via a plan → execute → report
round trip:

```
quad-client profile-device --model yolov8_det.onnx --transport adb
```

A QNN **context binary** (`.bin`) skips ONNX graph load entirely and is the
fastest on-device path; `convert_model` with `target_sdk="qnn"` and
`quantization="int8"` produces one. Worth measuring rather than assuming — as the
MiDaS w8a8 row above shows, quantization needs the right consumer to pay off.

---

## What we have not measured

The cane is built, assembled, and has been walked with — but these numbers have
not been captured yet, and they are the ones a reader will most want:

- **End-to-end reaction time**, obstacle entering frame → wheel torque. The
  assembly exists to measure it on; what remains is instrumenting the capture. It
  must include mechanical inertia, which no bench number here accounts for.
- **Battery life** under sustained motor load, phone charging from the same bank.
- **Steering accuracy or walking-speed effect.** The figures in the top-level
  README are the *research paper's* results for *their* device. This
  implementation has not been evaluated with users with impaired vision — informal
  walking by the team is not that.

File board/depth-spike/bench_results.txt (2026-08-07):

# input source: synthetic, threads=3, iters=12
{"model": "midas-float", "input": "256x256", "median_ms": 863.6, "p95_ms": 1022.6, "min_ms": 859.5, "fps": 1.16, "peak_mb": 197.4, "file_mb": 0.1}
{"model": "midas-w8a8", "input": "256x256", "median_ms": 1001.1, "p95_ms": 1009.1, "min_ms": 990.6, "fps": 1.0, "peak_mb": 156.9, "file_mb": 0.3}
{"model": "da-small", "input": "126x126", "median_ms": 451.8, "p95_ms": 453.0, "min_ms": 450.0, "fps": 2.21, "peak_mb": 212.8, "file_mb": 99.1}
{"model": "da-small", "input": "252x252", "median_ms": 1728.2, "p95_ms": 1731.5, "min_ms": 1723.6, "fps": 0.58, "peak_mb": 244.5, "file_mb": 99.1}
{"model": "da-small", "input": "378x378", "median_ms": 4172.1, "p95_ms": 4184.4, "min_ms": 4162.3, "fps": 0.24, "peak_mb": 303.3, "file_mb": 99.1}

========================================================================
PHASE 2 BENCHMARK  UNO Q / QRB2210  4xA53@2GHz  CPU-only  3 threads
========================================================================
model             input   median      p95    fps  peakMB  fileMB
----------------------------------------------------------------
midas-float     256x256     864m    1023m   1.16     197     0.1
midas-w8a8      256x256    1001m    1009m   1.00     157     0.3
da-small        126x126     452m     453m   2.21     213    99.1
da-small        252x252    1728m    1732m   0.58     244    99.1
da-small        378x378    4172m    4184m   0.24     303    99.1
========================================================================
DONE

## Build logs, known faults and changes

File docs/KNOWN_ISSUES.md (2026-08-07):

# Known issues

Findings from a source audit of the `v3` branch, verified against both the
Kotlin (phone) and Python (board) implementations. Documented rather than
silently fixed, because each needs hardware in hand to confirm the fix.

Severity: **S1** = affects steering behavior · **S2** = feature silently dead ·
**S3** = cosmetic or stale naming.

---

## S1 — `S` means STRAIGHT to the phone and STOP to the board

**Effect:** on a clear path the wheel is commanded to brake roughly every
200 ms, instead of being left free.

The phone emits one letter per decision window
(`CommandAggregator.kt:62-65`):

| Letter | Phone intent |
|---|---|
| `X` | STOP |
| `L` | LEFT |
| `R` | RIGHT |
| `S` | **STRAIGHT** |

The board lowercases the incoming token and looks it up in `ACTIONS`
(`host/qcane_btd.py:69-75`):

```python
ACTIONS = {
    "left": "left", "l": "left", ...
    "right": "right", "r": "right", ...
    "stop": "stop", "s": "stop", "x": "stop", "halt": "stop", ...
}
```

`L`, `R`, and `X` survive the round trip. **`S` lands on the `stop` alias** —
and no `straight` action exists on the board at all.

Why it hid: `S` is also the safety hello sent by `onReady()`, so
"park the wheel on connect" works exactly as intended, which makes the wire
traffic look correct in logs.

**Fix options.** Cleanest is to stop sending a letter for STRAIGHT at all —
"no lateral force" and "brake" are genuinely different states and the protocol
currently can't distinguish them. Alternatively add `"straight"`/`"n"` to
`ACTIONS` mapping to a coast/neutral action, and change the phone to send that.
Either way, keep `s` → stop so the safety hello still parks the wheel.

---

## S2 — The phone parses telemetry on a service that never sends it

**Effect:** `CaneBleLink.reading` never leaves `null`. Everything downstream of
the cane's distance sensor is dead code:

- `pathPipeline.grid.markNearObstacle(...)` — near-field obstacle fusion
- `haptics.caneStop()` — the phone's STOP buzz

There are two distinct BLE services in this system:

| Service | UUID base | Emits |
|---|---|---|
| **QCane GATT** (`host/qcane_btd.py`) | `bcf2f193-…` | `"left:5"` — wheel state, **no newline** |
| **Nordic UART bridge** (`board/ble-bridge/ble_bridge.py`) | `6e400001-…` | `{"mm":842,"p":1}\n` — distance JSON |

`CaneBleLink` names its constants `NUS_SERVICE_UUID` / `NUS_RX_UUID` /
`NUS_TX_UUID` but the values are the **QCane** UUIDs
(`CaneBleLink.kt:454-456`). So it connects to the wheel-control service and then
runs a newline-delimited JSON parser against `"left:5"`. Result: every real
state notification logs as `cane: unparseable line: left:5`, and the distance
stream it wants is on a service it never opens.

**Fix options.** Either (a) have `qcane_btd.py` forward distance telemetry onto
the QCane state characteristic as newline-terminated JSON, or (b) have the phone
maintain a second GATT connection to the Nordic UART bridge for sensor data
while keeping QCane for motor commands. (a) is less code and one radio link.

---

## S2 — The 1200 mm presence threshold is never sent

`OBSTACLE_THRESHOLD_MM = 1200` is declared at `CaneBleLink.kt:449` and
referenced **nowhere else in the tree**. `onReady()` writes only the safety
hello.

The board therefore keeps its own default, `PRESENCE_MAX_MM = 300.0`
(`board/qcane-wheel/python/main.py`). Obstacles register at 30 cm rather than the
documented 1.2 m — far too late to walk around at pace, which is the whole point
of the wider threshold.

**Fix:** write the threshold on connect, or set `PRESENCE_MAX_MM = 1200.0`
board-side. Note this is also gated behind the S2 issue above — the phone can't
currently confirm the `{"thr":"ack"}` response either.

---

## S2 — A phone that walks out of range leaves the wheel turning

`BleTransport` in `qcane_btd.py` subscribes to no BlueZ device-property signal,
so it never learns that the phone dropped off the GATT. The last command stands.

The board's 2 s failsafe does **not** cover this: `main.py` is still alive and
still re-sending the last known desired state 4×/s as its heartbeat. From the
MCU's point of view everything is healthy.

Consequence: lose the phone mid-turn and the wheel keeps steering until an
explicit `stop` arrives or the app dies. This is the most safety-relevant item
in this document.

**Fix:** watch `PropertiesChanged` on the BlueZ device object and zero the
command on disconnect. A phone-liveness timeout in `main.py` (distinct from the
existing MCU heartbeat) would be a belt-and-braces second layer.

---

## S3 — Grid lateral extent is narrower than planner ray range

`TraversabilityGrid` spans ±3.05 m laterally; `PolarPlanner.maxRangeM` is 5.5 m.
Peripheral raycasts therefore exit the mapped area and return "fully free" by
construction. Edge sectors are optimistic — a wide detour can be chosen partly
because nothing is known out there.

Not incorrect (unmapped genuinely isn't occupied), but "unknown" and "clear"
should probably not score identically when picking a valley.

---

## S3 — Stale comments and naming

| Location | Issue |
|---|---|
| `CaneBleLink.kt` | `NUS_*` constant names hold QCane UUIDs; KDoc mentions "Distance Watch"; one log tag still reads `qhackGPS` |
| `CommandAggregator.kt` | KDoc says "1 s failsafe"; the real board value is `COMMAND_TIMEOUT_MS = 2000`. Both board READMEs are correct — only the Kotlin comment is wrong |
| `dev.quad.shepherd` | Package and `ShepherdService` retain an earlier project name |
| `strings.xml` | `app_name` and notification text still show the earlier name on screen |

---

## Deliberately disabled, not broken

| Item | State | Why |
|---|---|---|
| Companion SLM | `COMPANION_ENABLED = false` | Qwen3.5-2B on Hexagon works (benchmarked 12.1 tok/s, 186 ms first token) but is off to keep NPU and thermal budget for the steering path. Flip the flag to demo it. |
| `BleCaneActuator` | Stub with a TODO | A 12-byte binary packet was designed, then superseded by the one-letter protocol over the board's own GATT. The stub is vestigial. |
| `NavEngine` | Unused | Earlier navigation iteration; `CompassNav` is the live one. |

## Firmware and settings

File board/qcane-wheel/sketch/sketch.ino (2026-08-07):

/*
 * qcane-wheel — MCU side (merged: wheel + distance + vibro).
 *
 * One sketch for the whole Modulino chain on the Qwiic bus (Wire1):
 *   UNO Q -> Modulino Motors -> Modulino Vibro -> Modulino Distance
 *
 * - Wheel: dir/speed arrive from the Linux side via "set_wheel" (phone over
 *   the QCane GATT, or the dashboard buttons). The 13x8 LED matrix mirrors
 *   what the motor is doing.
 * - Distance: every valid ToF measurement streams up as "distance_reading".
 * - Vibro: pulses in a rhythm while the Linux side holds "set_vibro" on
 *   (object inside the presence threshold); "vibro_pulse" fires one manual
 *   buzz from the dashboard.
 * - Failsafe: the Linux side re-sends the desired state 4x/s; if that stream
 *   stops for 2 s (app or bridge died), the wheel stops and the vibro goes
 *   quiet rather than run away.
 *
 * Wiring: the motor sits across terminals 1A and 2A, which is one half-bridge
 * from channel A and one from channel B rather than a single channel's own
 * pair, so the two channels have to be driven in opposite phase — see
 * driveMotor(). "motor_selftest" re-measures every option if that ever needs
 * checking again (streams "selftest_telemetry"; the periodic dashboard
 * stream is "motor_telemetry").
 */

#include <Arduino_LED_Matrix.h>
#include <Arduino_Modulino.h>
#include <Arduino_RouterBridge.h>

Arduino_LED_Matrix matrix;
ModulinoDistance distance;  // VL53L4CD/VL53L4ED time-of-flight sensor
ModulinoMotors motors;      // MAX22211 dual H-bridge; motor across 1A <-> 2A
ModulinoVibro vibro;        // haptic vibration motor

// Wheel speed 1..5 as a percentage of full scale. Starts high enough that a
// loaded motor actually turns instead of just buzzing.
static const uint8_t SPEED_PERCENT[5] = {30, 45, 60, 80, 100};

// The Linux side re-sends the desired actuator state 4x/s; if that stream
// stops (app or bridge died), stop every output rather than run away.
constexpr unsigned long COMMAND_TIMEOUT_MS = 2000;

// Proximity alert rhythm: a VIBRO_PULSE_MS buzz every VIBRO_PERIOD_MS.
constexpr unsigned long VIBRO_PULSE_MS = 250;
constexpr unsigned long VIBRO_PERIOD_MS = 500;

constexpr unsigned long MODULE_RETRY_MS = 3000;
constexpr unsigned long TELEMETRY_MS = 500;
constexpr unsigned long DISTANCE_POLL_MS = 20;

static const uint8_t MATRIX_W = 13;
static const uint8_t MATRIX_H = 8;
static const uint16_t MATRIX_PIXELS = MATRIX_W * MATRIX_H;  // 104

// Perimeter of the wheel, listed clockwise starting at the top-left of the top
// edge. Walking this list forwards looks like a clockwise spin, backwards like
// a counter-clockwise one.
static const uint8_t RING_LEN = 22;
static const uint8_t RING_ROW[RING_LEN] = {
    0, 0, 0, 0, 0, 1, 2, 3, 4, 5, 6, 7, 7, 7, 7, 7, 6, 5, 4, 3, 2, 1};
static const uint8_t RING_COL[RING_LEN] = {
    4, 5, 6, 7, 8, 9, 10, 10, 10, 10, 9, 8, 7, 6, 5, 4, 3, 2, 2, 2, 2, 3};

// Brightness of the spinning marker and the pixels trailing behind it
// (3-bit grayscale, so 0..7).
static const uint8_t COMET[] = {7, 5, 3, 1};
static const uint8_t COMET_LEN = sizeof(COMET);

// Module presence on the Qwiic bus (all three retried every 3 s).
static bool motorReady = false;
static bool sensorReady = false;
static bool vibroReady = false;

// Bridge handlers run on the bridge thread, loop() reads them — keep volatile.
volatile int wheelDir = 0;    // -1 = left, 0 = stopped, +1 = right
volatile int wheelSpeed = 5;  // 1 (slowest) .. 5 (full scale)
volatile bool dirty = true;
volatile int selftestPercent = 0;   // > 0 asks loop() to run the self-test
volatile bool desiredVibro = false;
volatile int pendingPulseMs = 0;    // one-shot manual buzz from the dashboard
volatile unsigned long lastCommandMs = 0;

static uint8_t frame[MATRIX_PIXELS];
static int head = 0;
static unsigned long lastStep = 0;

// Last command loop() acted on, so transitions are handled exactly once.
// Seeded to an impossible value so the current state is reported once at boot.
static int appliedDir = -99;
static int appliedSpeed = -99;

static bool vibroActive = false;
static unsigned long lastPulseMs = 0;
static unsigned long lastRetryMs = 0;
static unsigned long lastTelemetryMs = 0;
static unsigned long lastStatusMs = 0;
static unsigned long lastDistancePollMs = 0;
static float lastMm = NAN;

static inline void px(uint8_t row, uint8_t col, uint8_t level) {
  if (row < MATRIX_H && col < MATRIX_W) {
    frame[row * MATRIX_W + col] = level;
  }
}

// Animation step delay: higher speed spins faster.
static uint16_t stepIntervalMs(int speed) {
  switch (speed) {
    case 1:  return 220;
    case 2:  return 150;
    case 3:  return 100;
    case 4:  return 70;
    default: return 45;
  }
}

static void renderWheel() {
  memset(frame, 0, sizeof(frame));

  int dir = (appliedDir == -99) ? 0 : appliedDir;

  // Faint rim, so the wheel stays visible even when stopped.
  for (uint8_t i = 0; i < RING_LEN; i++) {
    px(RING_ROW[i], RING_COL[i], 1);
  }

  if (dir == 0) {
    // Stopped: bright hub, no motion.
    px(3, 5, 3); px(3, 6, 5); px(3, 7, 3);
    px(4, 5, 3); px(4, 6, 5); px(4, 7, 3);
    return;
  }

  px(3, 6, 2);
  px(4, 6, 2);

  // Two markers half a turn apart read as rotation much better than one.
  for (uint8_t spoke = 0; spoke < 2; spoke++) {
    for (uint8_t t = 0; t < COMET_LEN; t++) {
      int idx = head + (spoke * (RING_LEN / 2)) - (dir * (int)t);
      idx = ((idx % RING_LEN) + RING_LEN) % RING_LEN;
      px(RING_ROW[idx], RING_COL[idx], COMET[t]);
    }
  }

  // Bar on the edge of the panel we are turning towards.
  uint8_t col = (dir < 0) ? 0 : (MATRIX_W - 1);
  for (uint8_t row = 2; row <= 5; row++) {
    px(row, col, 6);
  }
}

// Convert a wheel speed of 1..5 into a raw signed H-bridge value.
static int16_t rawForSpeed(int speed) {
  uint8_t percent = SPEED_PERCENT[constrain(speed, 1, 5) - 1];
  return (int16_t)((int32_t)percent * ModulinoMotors::MAX_SPEED / 100);
}

// Signed duty percentage the H-bridge applies for the current wheel state.
static int appliedDutyPct() {
  if (appliedDir == -99 || appliedDir == 0 || appliedSpeed < 1) {
    return 0;
  }
  return appliedDir * SPEED_PERCENT[constrain(appliedSpeed, 1, 5) - 1];
}

// Drive the wheel. Called from loop() once per command, not per animation
// frame, so the I2C traffic stays proportional to commands rather than frames.
static void driveMotor(int dir, int speed) {
  if (!motorReady) {
    return;
  }
  if (dir == 0) {
    motors.stop();
    return;
  }

  // The motor bridges terminal 1A (channel A) and 2A (channel B), so it only
  // sees a voltage when the two channels are pushed in opposite directions.
  int16_t raw = rawForSpeed(speed);
  motors.setDcSpeedRaw(dir > 0 ? raw : (int16_t)-raw,
                       dir > 0 ? (int16_t)-raw : raw);
}

// Sample the current sensors and hand the numbers to the Linux side. Used by
// the self-test to work out which terminals the motor is actually on: only a
// channel with the motor across it draws current.
static void reportCurrent(const char* stage) {
  delay(500);  // let the new drive state settle before sampling
  float milliampsA = -1.0f;
  float milliampsB = -1.0f;
  String mode = "?";
  bool busy = false;
  if (motors.update()) {
    milliampsA = motors.sensedCurrentA();
    milliampsB = motors.sensedCurrentB();
    // Reading the mode back proves the module is acting on what we send,
    // which separates "not listening" from "listening but unpowered".
    mode = motors.stepperModeEnabled() ? "stepper" : "dc";
    busy = motors.busy();
  }
  Bridge.notify("selftest_telemetry", String(stage), milliampsA, milliampsB,
                mode, busy);
}

// Try every sensible way of driving the two channels and report the current
// each one draws. Runs from loop(), so it is free to block.
static void runSelftest(int percent) {
  if (!motorReady) {
    Bridge.notify("selftest_telemetry", String("no modulino found"),
                  -1.0f, -1.0f, String("?"), false);
    return;
  }

  int16_t raw = (int16_t)((int32_t)constrain(percent, 10, 100)
                          * ModulinoMotors::MAX_SPEED / 100);

  // Half-full-scale doubles the current-sense resolution (~0.65 mA per count
  // instead of ~1.3), which matters when we are looking for "any current".
  motors.setHalfFullScaleEnabled(true);

  motors.stop();
  reportCurrent("idle");
  motors.setDcSpeedRaw(raw, 0);
  reportCurrent("A+ only (1A/1B)");
  motors.setDcSpeedRaw(0, raw);
  reportCurrent("B+ only (2A/2B)");
  motors.setDcSpeedRaw(raw, (int16_t)-raw);
  reportCurrent("A+/B- (1A -> 2A)");
  motors.setDcSpeedRaw((int16_t)-raw, raw);
  reportCurrent("A-/B+ (2A -> 1A)");
  motors.stop();
  reportCurrent("stopped");

  motors.setHalfFullScaleEnabled(false);

  // Put the wheel back where the app last left it.
  driveMotor(appliedDir == -99 ? 0 : appliedDir, appliedSpeed < 1 ? 5 : appliedSpeed);
}

static bool beginMotors() {
  if (!motors.begin()) {
    return false;
  }
  motors.setStepperModeEnabled(false);  // DC, not stepper
  motors.setDecay(ModulinoMotors::DecayMode::SLOW);
  motors.stop();
  // Force the next loop() pass to re-apply and re-report the wheel state.
  appliedDir = -99;
  appliedSpeed = -99;
  return true;
}

// Called from Python: Bridge.call("set_wheel", dir, speed).
//
// This runs on the bridge thread, in the middle of an RPC request, so it only
// touches state. Logging here would be a nested RPC (Monitor.write() calls
// back over the same bridge) and driving hardware would stall the request —
// both are handled from loop() instead.
void set_wheel(int dir, int speed) {
  int d = (dir > 0) ? 1 : ((dir < 0) ? -1 : 0);
  int s = constrain(speed, 1, 5);
  // The Linux side re-sends this 4x/s as a heartbeat; only redraw on change.
  if (d != wheelDir || s != wheelSpeed) {
    dirty = true;
  }
  wheelDir = d;
  wheelSpeed = s;
  lastCommandMs = millis();
}

void set_vibro(int on) {
  desiredVibro = (on != 0);
  lastCommandMs = millis();
}

void vibro_pulse(int ms) {
  pendingPulseMs = constrain(ms, 50, 3000);
}

// Called from Python: Bridge.call("motor_selftest", percent). Same rule as
// set_wheel — only set a flag; loop() does the blocking work.
void motor_selftest(int percent) {
  selftestPercent = constrain(percent, 10, 100);
}

void setup() {
  matrix.begin();
  matrix.setGrayscaleBits(3);  // 8 brightness levels (0..7)
  matrix.clear();

  // Initialize Modulino I2C communication (Qwiic connector is on Wire1)
  Modulino.begin(Wire1);
  motorReady = beginMotors();
  sensorReady = distance.begin();
  vibroReady = vibro.begin();

  Bridge.begin();
  Monitor.begin();

  bool ok = Bridge.provide("set_wheel", set_wheel);
  ok = Bridge.provide("set_vibro", set_vibro) && ok;
  ok = Bridge.provide("vibro_pulse", vibro_pulse) && ok;
  ok = Bridge.provide("motor_selftest", motor_selftest) && ok;
  Monitor.print("[qcane-wheel] sketch ready, bridge=");
  Monitor.print(ok ? "yes" : "no");
  Monitor.print(" motors=");
  Monitor.print(motorReady ? "found" : "MISSING");
  Monitor.print(" distance=");
  Monitor.print(sensorReady ? "found" : "MISSING");
  Monitor.print(" vibro=");
  Monitor.println(vibroReady ? "found" : "MISSING");

  renderWheel();
  matrix.draw(frame);
}

void loop() {
  unsigned long now = millis();

  if (selftestPercent > 0) {
    int percent = selftestPercent;
    selftestPercent = 0;
    runSelftest(percent);
    lastStep = millis();
  }

  // Look again every 3 s for any module that is missing (supports hot-plug)
  if ((!motorReady || !sensorReady || !vibroReady) && (now - lastRetryMs >= MODULE_RETRY_MS)) {
    lastRetryMs = now;
    if (!motorReady) {
      motorReady = beginMotors();
      if (motorReady) {
        Monitor.println("[qcane-wheel] Modulino Motors connected");
      }
    }
    if (!sensorReady) {
      sensorReady = distance.begin();
      if (sensorReady) {
        Monitor.println("[qcane-wheel] Modulino Distance connected");
      }
    }
    if (!vibroReady) {
      vibroReady = vibro.begin();
      if (vibroReady) {
        Monitor.println("[qcane-wheel] Modulino Vibro connected");
      }
    }
  }

  // available() is true only when a NEW valid measurement arrived; no target
  // in range produces no data at all. Gated so the animation's 5 ms loop does
  // not multiply the I2C traffic.
  if (sensorReady && (now - lastDistancePollMs >= DISTANCE_POLL_MS)) {
    lastDistancePollMs = now;
    if (distance.available()) {
      lastMm = distance.get();
      Bridge.notify("distance_reading", lastMm);
    }
  }

  // Failsafe: without fresh commands from the Linux side, stop everything.
  int effDir = wheelDir;
  int effSpeed = wheelSpeed;
  bool vibroTarget = desiredVibro;
  if (lastCommandMs == 0 || (now - lastCommandMs) > COMMAND_TIMEOUT_MS) {
    effDir = 0;
    vibroTarget = false;
  }

  // React to a new command: drive the motor, tell Python what actually got
  // applied, and log. All of it outside the bridge handler, where blocking and
  // nested RPCs are safe.
  if (effDir != appliedDir || effSpeed != appliedSpeed) {
    appliedDir = effDir;
    appliedSpeed = effSpeed;

    driveMotor(effDir, effSpeed);

    // Fire-and-forget, so a Python side that is not listening cannot stall us.
    // motorReady rides along so the app can flag a missing Modulino.
    Bridge.notify("wheel_applied", effDir, effSpeed, motorReady);

    Monitor.print("[wheel] dir=");
    Monitor.print(effDir);
    Monitor.print(" speed=");
    Monitor.println(effSpeed);
    dirty = true;
  }

  // Proximity haptics: rhythmic pulses while an object is inside the
  // threshold. Each pulse self-terminates after VIBRO_PULSE_MS, so a wedged
  // loop cannot leave the vibro buzzing.
  if (vibroReady) {
    if (vibroTarget) {
      if (!vibroActive || (now - lastPulseMs) >= VIBRO_PERIOD_MS) {
        vibro.on(VIBRO_PULSE_MS);
        lastPulseMs = now;
        vibroActive = true;
      }
    } else if (vibroActive) {
      vibro.off();
      vibroActive = false;
    }

    // One-shot manual buzz requested from the dashboard
    int pulse = pendingPulseMs;
    if (pulse > 0) {
      pendingPulseMs = 0;
      vibro.on((size_t)pulse);
    }
  } else {
    pendingPulseMs = 0;  // drop manual requests while the module is missing
  }

  // 2 Hz motor telemetry for the dashboard: current sense per channel (mA),
  // what the sketch is actually applying (direction + signed duty), and the
  // driver busy flag. The firmware does not report VM voltage; the signed
  // duty is the applied differential output as a fraction of VM.
  if (motorReady && (now - lastTelemetryMs >= TELEMETRY_MS)) {
    lastTelemetryMs = now;
    if (motors.update()) {
      Bridge.notify("motor_telemetry",
                    motors.sensedCurrentA(),
                    motors.sensedCurrentB(),
                    appliedDir == -99 ? 0 : appliedDir,
                    appliedDutyPct(),
                    vibroActive ? 1 : 0,
                    motors.busy() ? 1 : 0);
    }
  }

  // 1 Hz heartbeats so the Linux side can tell "no object" apart from "no
  // sensor" and can show which modules are attached.
  if (now - lastStatusMs >= 1000) {
    lastStatusMs = now;
    Bridge.notify("sensor_status", sensorReady);
    Bridge.notify("actuator_status", (motorReady ? 1 : 0) | (vibroReady ? 2 : 0));
  }

  if (appliedDir != 0 && appliedDir != -99
      && (now - lastStep) >= stepIntervalMs(appliedSpeed)) {
    lastStep = now;
    head = ((head + appliedDir) % RING_LEN + RING_LEN) % RING_LEN;
    dirty = true;
  }

  if (dirty) {
    dirty = false;
    renderWheel();
    matrix.draw(frame);
  }

  delay(5);
}

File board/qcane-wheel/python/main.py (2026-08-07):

"""qcane-wheel — Linux (MPU) side (merged: wheel + distance + vibro + dashboard).

Bluetooth itself lives in host/qcane_btd.py, which runs on the host rather than
in this container: the app container is on a Docker bridge network with no
D-Bus and no AF_BLUETOOTH, so it cannot reach BlueZ. The daemon owns the radio
and hands phone commands over a Unix socket in the app folder (bind-mounted at
/app); this module folds them into the same policy pipeline as the dashboard.

Policy lives here: presence (mm <= threshold) drives the vibro, the last
wheel command (phone or dashboard, last writer wins) drives the motor, and
both are re-sent to the sketch 4x/s as the failsafe heartbeat. The web
dashboard (port 7000) shows per-Modulino informatics and manual controls.
"""

import json
import os
import select
import socket
import threading
import time
from collections import deque

from arduino.app_utils import App, Bridge, Logger
from arduino.app_bricks.web_ui import WebUI

logger = Logger("qcane-wheel")

# An object closer than this counts as "in front" and lights the red lamp.
PRESENCE_MAX_MM = 300.0
# No valid reading for this long -> report "nothing in range".
STALE_AFTER_S = 1.0
# Cap reading-driven websocket pushes (the sensor streams at up to ~50 Hz).
EMIT_MIN_INTERVAL_S = 0.05
# Dashboard event log depth.
EVENT_LOG_LEN = 30
# Motor telemetry history depth for the dashboard graphs (2 Hz -> 2 minutes).
MOTOR_HISTORY_LEN = 240
# Motor supply voltage wired into the Modulino Motors VM terminals. The module
# cannot measure VM, so the dashboard computes applied volts as duty x VM.
MOTOR_VM_V = 5.0

# Bluetooth daemon (QCane GATT) unix socket, served by host/qcane_btd.py.
SOCKET_PATH = os.environ.get("QCANE_BT_SOCKET", "/app/.run/qcane-bt.sock")
SOCKET_RETRY_S = 2.0
MAX_BUFFER = 64 * 1024

# Sketch-side convention for set_wheel(dir, speed).
DIRECTIONS = {"left": -1, "stop": 0, "right": 1}
ACTION_NAMES = {value: name for name, value in DIRECTIONS.items()}
DEFAULT_SPEED = 5    # phone commands without a speed: full scale
DASHBOARD_SPEED = 5  # dashboard buttons always drive full scale

# Dodge flip: a RIGHT turn that has run for ~this much arc with the obstacle
# still inside the presence threshold has exhausted that side — swing LEFT
# instead. The wheel has no yaw sensor, so arc is a time proxy: full-scale
# spin yaws the cane at roughly WHEEL_YAW_DEG_PER_S (estimate — tune on the
# real cane), so 60 deg ~= 3 s. The timer re-arms whenever the wheel leaves
# RIGHT or the path clears, and any later phone/dashboard command still wins
# (last writer, as always).
DODGE_FLIP_DEG = 60.0
WHEEL_YAW_DEG_PER_S = 20.0
DODGE_FLIP_AFTER_S = DODGE_FLIP_DEG / WHEEL_YAW_DEG_PER_S

ui = WebUI()

_lock = threading.Lock()
_state = {
    "mm": None,          # latest valid reading from the sensor, millimeters
    "present": False,    # True while an object is within the presence threshold
    "sensor_ok": False,  # True once the sketch reports the Modulino is detected
    "count": 0,          # valid readings received since app start
    "hz": 0.0,           # measured reading rate
    "threshold_mm": PRESENCE_MAX_MM,
    "phone_msg": None,   # last freeform text received over the NUS side channel
    "motor": 0,          # commanded wheel direction: -1 left, 0 stop, +1 right
    "wheel_speed": DASHBOARD_SPEED,  # commanded wheel speed 1..5
    "motors_ok": False,  # True once the sketch reports the Modulino Motors is detected
    "vibro_ok": False,   # True once the sketch reports the Modulino Vibro is detected
    "motor_ma_a": None,  # sensed current on channel A, mA
    "motor_ma_b": None,  # sensed current on channel B, mA
    "motor_applied": 0,  # direction the sketch is actually applying right now
    "speed_applied": 0,  # speed the sketch is actually applying right now
    "motor_duty_pct": 0, # signed duty the sketch applies = voltage as % of VM
    "motor_t": None,     # epoch seconds of the latest motor telemetry sample
    "vm_v": MOTOR_VM_V,  # configured VM supply voltage (volts)
    "graph_epoch": 0,    # bumped when the graphs are cleared; clients drop buffers
    "motor_busy": False, # driver busy flag from module telemetry
    "vibro_active": False,  # True while the sketch is running the pulse rhythm
    "cane_daemon": False,   # True while the QCane BT daemon socket is connected
    "bt": {"advertising": False, "connected": False, "device": None},
    "events": [],        # rolling event log, newest last
}
_events = deque(maxlen=EVENT_LOG_LEN)
_motor_history = deque(maxlen=MOTOR_HISTORY_LEN)
_last_reading_t = 0.0
_bt_last_t = 0.0
_last_emit_t = 0.0
_win_start_t = time.monotonic()
_win_count = 0

_sock = None
_sock_buffer = b""
_sock_last_try = 0.0
_sock_last_warn = 0.0


def _snapshot(history: bool = False) -> dict:
    """State snapshot. The motor graph history rides along only on demand
    (initial websocket push + GET /api/state) — live updates append
    client-side from the regular state stream."""
    with _lock:
        snap = dict(_state)
        snap["events"] = list(_events)
        if history:
            snap["motor_history"] = list(_motor_history)
    snap["age_ms"] = int((time.monotonic() - _last_reading_t) * 1000) if _last_reading_t else None
    return snap


def _emit(force: bool = False):
    global _last_emit_t
    now = time.monotonic()
    if not force and (now - _last_emit_t) < EMIT_MIN_INTERVAL_S:
        return
    _last_emit_t = now
    try:
        ui.send_message("distance", _snapshot())
    except Exception:
        logger.debug("Failed to emit 'distance' websocket message")


def _log_event(msg: str):
    """Append to the dashboard event log (and the app log), then push."""
    with _lock:
        _events.append({"t": time.strftime("%H:%M:%S"), "msg": msg})
    logger.info(msg)
    _emit(force=True)


# ---- Bluetooth daemon (QCane GATT) socket -----------------------------------

def _sock_disconnect():
    global _sock, _sock_buffer
    sock = _sock
    if sock is not None:
        try:
            sock.close()
        except OSError:
            pass
    _sock = None
    _sock_buffer = b""
    with _lock:
        changed = _state["cane_daemon"]
        _state["cane_daemon"] = False
    if changed:
        _log_event("QCane Bluetooth daemon disconnected")


def _sock_send(payload: dict):
    """Report back to the daemon so it can push state to the phone.

    Also called from the Bridge thread, so take a local reference: the main
    loop may drop the connection concurrently."""
    sock = _sock
    if sock is None:
        return
    try:
        sock.sendall((json.dumps(payload) + "\n").encode("utf-8"))
    except OSError as err:
        logger.warning(f"could not send {payload.get('type')} upstream: {err}")
        _sock_disconnect()
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

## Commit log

2026-08-04 Initial Shepherd Snapdragon app: NPU object detection + assistive guidance for Galaxy S25 Ultra
    CameraX -> ONNX Runtime QNN EP (Hexagon NPU) YOLOv8 detection, column-based
    gap-seeking guidance with TTS + haptics, optional Claude scene narration,
    BLE cane actuator stub, JVM unit tests, AI Hub model fetch scripts, and
    QUAD profiling docs.
    [MainActivity.kt]
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2026-08-05 Upgrade toolchain for Android Studio's Gradle 9 / JDK 25 environment
    The original AGP 8.5.2 + Kotlin 1.9.24 pins crashed the Kotlin daemon
    ('Daemon compilation failed: null') under the Gradle 9.3 wrapper Studio
    generated and its bundled JDK 25. Upgrades, each demanded by the next
    build error:
    - AGP 8.5.2 -> 9.3.1 (current stable)
    - Gradle wrapper 9.3.0 -> 9.5.0 (AGP 9.3 minimum)
    - Remove org.jetbrains.kotlin.android plugin: AGP 9 has built-in Kotlin
    and errors if the standalone plugin is applied
    - packaging.resources excludes for META-INF duplicates from the Anthropic
    SDK's Apache HTTP transitive jars
    Verified locally: gradlew :app:assembleDebug :app:testDebugUnitTest
    passes (APK packa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
2026-08-05 Add dense depth sensing: Depth-Anything-V2 on the NPU + close-range fixes
    Fixes 'very close obstacles do not warn': the detector only knows 80 COCO
    classes (walls/poles/doors are invisible), unknown classes defaulted to a
    safe 4 m, and truncated boxes made the pinhole model overestimate exactly
    when objects were closest.
    - DepthEngine: Depth-Anything-V2-Small (Apache-2.0, exported locally via
    scripts/export_depth_model.sh; asset not committed, ~99 MB) as a second
    ONNX Runtime QNN session. Per-column near-field disparity from the
    corridor band + scene median.
    - DepthCalibrator: fits disparity = a/z + b against pinhole distances of
    known-height detections (EMA-smoothed); scene-relativ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
    [MainActivity.kt]
2026-08-05 Fix NPU never engaging + depth latency + wall-fills-view blind spot
    Logcat showed QNN_DEVICE_ERROR_INVALID_CONFIG on every session: QNN's SoC
    auto-detect fails on the S25 Ultra's SM8750-AC ('for Galaxy') variant, and
    ORT then silently ran BOTH models on CPU while our label claimed NPU
    (hence 800 ms/frame).
    - OrtSessions: shared factory passing soc_model=69 / htp_arch=79
    explicitly, with an honest three-tier fallback — tier 1 sets
    session.disable_cpu_ep_fallback so only a fully-NPU-compiled graph may
    report 'NPU'; then 'NPU/CPU mixed'; then 'CPU'.
    - Depth model re-exported at 294x294 (~6x less transformer compute;
    152 ms even on WSL CPU vs ~800 on-device at 518). DepthEngine now re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
2026-08-05 Overhaul speech, guidance stability, and depth: metric model + announcement policy
    Field testing surfaced three failures:
    1. 'obs- obs- obs-' stutter: urgent messages bypassed rate limiting AND
    the spoken distance changed every frame, so DANGER flushed and
    restarted TTS at frame rate.
    2. Guidance whiplash: raw per-frame severity/steer with no temporal
    smoothing; danger bypassed hysteresis by design.
    3. Walls/doors dead ahead unreported: relative-depth models have
    per-frame scale, so the global disparity->meters fit was unsound, and
    the temporal-baseline trick cannot see a wall you are already facing.
    Changes:
    - AnnouncementPolicy (new, pure, 8 tests): quantizes distances to 0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
    [MainActivity.kt]
2026-08-05 Depth debug view, vendor native-library declarations, ORT 1.28
    - Logcat showed the REAL accelerator blocker: Android's namespace rules
    deny QNN's backends their vendor libraries unless the manifest declares
    them. libQnnGpu.so could not dlopen libOpenCL.so (explicit linker
    error), and HTP's libcdsprpc.so (FastRPC to the Hexagon) is the same
    class of failure — likely the QNN_DEVICE_ERROR_INVALID_CONFIG root
    cause all along. Added <uses-native-library> for both.
    - ONNX Runtime 1.27 -> 1.28 (newer bundled QNN SDK).
    - OrtSessions: GPU/CPU-mixed tier between full-GPU and mixed-NPU.
    - Depth debug view ('Depth' switch): colorized metric depth map (red=near,
    blue=far, fixed 0.3-6 m ramp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
    [MainActivity.kt]
2026-08-05 GenieX SLM integration (step 0) + voice arbiter v2 (phase 0)
    Toward the conversational companion (scoped with the user): on-device SLM
    via Qualcomm GenieX, with the deterministic safety channel unchanged.
    - GenieX 0.3.16 from Maven Central (pulls QNN 2.42). Native-lib collision
    with onnxruntime's bundled QNN resolved via jniLibs pickFirsts with
    GenieX declared first — ORT now loads the newer QNN 2.42 libs (worth
    watching: may change the vision NPU story).
    - llm/GenieBench: step-0 bake-off harness. Long-press 'Describe scene'
    pulls unsloth/Qwen3.5-2B-GGUF (Q4_0, ~1.2 GB, on-device download via
    GenieX) and benchmarks generation on NPU, GPU, and CPU: first-token
    latency + decode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
    [MainActivity.kt]
2026-08-05 Make the SLM bench reachable: bench button was disabled without an API key
    The step-0 benchmark was hooked to a long-press of the Describe button,
    but that button was disabled whenever no Claude key is configured — and
    Android drops all input on disabled views, so the bench (and the model
    download it triggers) was unreachable. The button is now always enabled:
    long-press runs the benchmark, short-press without a key shows a hint,
    and its label says 'Hold: run on-device LLM benchmark'.
    [MainActivity.kt]
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2026-08-05 Fix recognizer error 13: auto-download the on-device speech model
    The S25 Ultra shipped with no on-device recognition language packs at all
    (installed=[]), so every startListening ended in ERROR_LANGUAGE_UNAVAILABLE
    (13). VoiceInput now checks RecognitionSupport at startup and triggers the
    system download for the current locale when the pack is missing, announces
    the download instead of a raw error code, and maps the language error codes
    to spoken, human messages.
    [MainActivity.kt]
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2026-08-05 Background service, smarter companion, OCR, self-provisioning, cleanup
    The whole pipeline (camera, vision, guidance, blackboard, SLM, speech) now
    lives in ShepherdService, a camera foreground service — haptic guidance
    and the companion survive the screen turning off or the phone going into
    a pocket. MainActivity is a thin bound shell: preview, overlay, steering
    panel, push-to-talk. Volume-down is a second PTT trigger (eyes-free,
    works under TalkBack).
    Companion fixes: the system prompt no longer scene-grounds general
    knowledge (asked the capital of France, it refused because "no signs
    visible" — now only surroundings questions use scene facts); history
    trimmed to 6 turns to cut prefill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
    [MainActivity.kt]
2026-08-05 Walking navigation with obstacle-fused steering; latency fixes
    Navigation (mirrors the original Shepherd's architecture): say "take me
    to <place>" — Geocoding + Google Routes API (walking, per-step polylines
    + instructions) feed RouteTracker, which turns each GPS fix + compass
    heading into a look-ahead steering bias, turn cues ("Turn right onto…"),
    arrival detection, and off-route strikes that trigger automatic
    rerouting (the continually-updated path finding). SteerFusion blends the
    route bias into obstacle steering additively scaled by (1 - proximity),
    exactly like Shepherd: danger ignores the map, close obstacles mute it,
    clear paths follow it. The fused command drives SteerView and th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
    [MainActivity.kt]
2026-08-05 Debug console, route mini-map, directional haptics
    Evaluation tooling: a "Log" switch in the top bar overlays a live
    decision feed — heard transcript, intent routing (NAV vs SLM), SLM
    first-token/total timings, TTS engine + synth ms, navigation events,
    danger decisions, vision backend, thermal — via util/DebugLog (also
    tagged ShepherdDebug in logcat).
    Navigation gets a lite-mode Google Map (top-right, only while a route is
    active): blue route polyline, destination pin, live position marker,
    auto-fit camera. Needs "Maps SDK for Android" enabled on the key.
    Directional haptics (requested this time): LEFT = two short taps,
    RIGHT = one long buzz, STOP = two strong buzzes, caution = single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
    [MainActivity.kt]
2026-08-05 Fix mini-map zoom: use the explicit-dimensions bounds overload
    The camera was framed the moment the map view flipped from GONE to
    VISIBLE — before its first layout pass — so newLatLngBounds computed
    zoom against a zero-sized viewport and showed the whole state. The
    (bounds, width, height, padding) overload takes the map's fixed 160dp
    square explicitly and frames the route correctly regardless of layout
    timing.
    [MainActivity.kt]
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2026-08-06 qhackGPS: compass navigation with Bluetooth guidance export
    Tap-to-set destination with walking routes (Directions API, straight-line
    fallback), camera-pointing compass guidance (green light within 15 degrees,
    left/right turn arrows with degrees), 5 Hz SPP frames to an Arduino motor
    controller with failsafe heartbeat, broadcast intents for sibling components
    of the larger assured-navigation system, and a ready-to-flash Arduino sketch.
    Claude-Session: https://claude.ai/code/session_01WopWo6iAW6LZEzXczbhVfx
    [MainActivity.kt]
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2026-08-06 Integrate qhackcane obstacle sensor over BLE; steer around objects
    CaneBleLink: BLE central that auto-discovers the cane's Nordic UART
    peripheral (Distance Watch), subscribes to the distance stream, sets the
    presence threshold to 1200 mm on connect, and auto-reconnects. While the
    cane reports an object in the way, the HUD shows the live distance and a
    left/right dodge (side chosen toward the route target, latched until
    clear), the exported SPP frames and broadcasts carry the avoidance turn
    plus new obstacle fields (protocol v2, backward compatible), and the
    avoidance state is mirrored to the cane dashboard.
    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
    [MainActivity.kt, qhack_guidance_motor.ino]
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2026-08-06 Auto-connect to the Arduino; buzz the phone to stop for obstacles
    The serial link no longer needs anyone to tap BT: on launch the app asks for
    the Bluetooth runtime permissions alongside GPS, then picks the paired device
    that worked last time (remembered in prefs), else one whose name looks like a
    serial module, else any paired device that isn't obviously a headset or watch.
    Failed candidates rotate every 4 s on the existing retry clock, so a module
    that's powered up late still gets found. Tapping BT now only overrides the
    pick or disconnects, and an explicit disconnect switches auto-connect off.
    Obstacles now stop the user instead of only steering them: while the cane
    reports an object the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
    [MainActivity.kt]
2026-08-06 Fix unreadable HUD in dark mode; make the stop buzz far stronger
    The HUD cards passed `colorScheme.surface.copy(alpha = 0.95f)` as their
    container. An alpha copy no longer matches any scheme colour, so Material3's
    contentColorFor() returned Unspecified and text fell back to LocalContentColor
    — black. On a phone in dark mode that painted black text on a near-black card.
    Rather than patch the alpha, the HUD now pins its own palette and passes
    contentColor explicitly. It floats over a map, is read at a glance while
    walking, and is often in sunlight: it should not follow the system scheme at
    all. White paper, near-black ink, saturated signal colours, bigger and heavier
    type, an 84dp status li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
    [MainActivity.kt]
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2026-08-07 Field-test round: Wayfinder columns, ground self-cal, roll, preview fix
    Live corridor testing (screenshots via adb) drove four fixes:
    - Always-STOP root causes: ground-level classification now
    self-calibrates per frame (25th-percentile height across the whole
    frame — robust to camera-height error and phone roll), and seg-only
    "soft obstacle" evidence saturates below the blocking threshold so
    out-of-domain indoor floors can't become walls.
    - Wayfinder's walkable-fraction columns (ported to the NPU FFNet as
    path/WalkableColumns) arbitrate STOPs: geometry-only stop + clearly
    open seg corridor -> cautious steer toward it instead of freezing.
    Verified: corridor scene now plans ST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
    [MainActivity.kt]
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2026-08-07 Map-first UI with heading arrow; fix camera stall behind hidden preview
    The map is now the default full-screen view (qhackgps-style): camera +
    depth heatmap live behind the Depth toggle, the BEV traversal minimap
    and threat bar float over the map (OverlayView mapMode skips frame-space
    drawings; grid renders always). The user marker is a flat arrow bitmap
    rotated by the compass heading, live from app start (CompassNav
    startPassive). Beeline + destination pin unchanged.
    Two field fixes: PreviewView must be INVISIBLE, not GONE — without its
    surface CameraX never configures the capture session and the ANALYSIS
    stream starves too (status froze at "Loading detection model…"); and a
    phone rebo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
    [MainActivity.kt]
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2026-08-07 Add Modulino Motors steering and Vibro proximity haptics
    The Qwiic chain is now UNO Q -> Modulino Motors -> Vibro -> Distance.
    While an object is inside the presence threshold, the vibro pulses
    (250 ms every 500 ms). Phone BLE text containing left/right spins the
    DC motor on Motors channel A (screw terminals 1A/2A); clear/stop stops
    it — so qhackGPS's AVOID LEFT / AVOID RIGHT / CLEAR steer physically.
    Python owns the policy (vibro = presence, motor = last phone command)
    and re-sends the desired state to the sketch 4x/s over the Bridge; the
    sketch stops every output if that stream goes quiet for 2 s, and the
    motor is also zeroed when the phone disconnects or the BLE bridge dies.
    All three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
    [main.py, sketch.ino]
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2026-08-07 QCane Link dashboard: per-Modulino informatics + manual motor/vibro controls
    The web page becomes a link dashboard with a card per module: distance
    (reading, rate, age, threshold), motors (sensed current per channel in
    mA — VM voltage is not in the fw telemetry — commanded vs applied
    direction, busy flag), vibro (detect + buzzing state), Bluetooth link,
    and a rolling 30-entry event log fed by every state transition.
    Manual controls: spin left / stop / spin right (POST /api/motor) and a
    one-shot vibro buzz (POST /api/vibro), riding the same failsafe
    heartbeat path as phone commands. Sketch adds 2 Hz motor_telemetry
    (motors.update() current sense) and a vibro_pulse mailbox handler.
    Verif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
    [app.js, main.py, sketch.ino]
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2026-08-07 Fix grid ground-latch + steering drift; halve pipeline latency
    Field session showed a solid-red BEV grid, always-right steering, and
    413 ms frames. Root causes and fixes:
    - Ground self-calibration sampled only the TOP image rows (fixed stride
    filled the 512-sample cap before reaching the floor), so pitched at a
    desk the ground latched onto the desk plane and the whole room became
    an obstacle field. Frame-proportional stride + p12 + EMA, keep last
    good estimate when the sanity gate fails.
    - Depth model hallucinated geometry for the letterbox padding (25% of
    the square); those pixels are now NaN-masked before the grid, ground
    estimate, near-field columns, and box medians see them.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
    [MainActivity.kt]
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2026-08-07 Outdoor/indoor nav modes: Google walking routes vs straight-line
    New "Outdoor" toggle (top bar, default on) and voice intents
    ("outdoor mode" / "indoor mode"):
    - OUTDOOR: fetches the actual walking route via the v1 RoutesClient
    (Routes API v2) and follows it with RouteTracker - goal angle aims at
    a look-ahead point along the street path, spoken turn cues, off-route
    rerouting, arrival. The map draws the full route polyline. Any fetch
    failure falls back to the beeline with a spoken notice.
    - INDOOR: the qhackgps straight-line compass bearing, unchanged - GPS
    routing knows nothing about corridors.
    Route follower advances once per GPS fix (events paced by position, not
    the 15 Hz comp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
    [MainActivity.kt]
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2026-08-07 Merge distance-watch into qcane-wheel: one app for the whole cane board
    The qcane-wheel app now owns all three Modulinos. Sketch: qcane's
    cross-channel wheel drive (motor spans 1A<->2A, opposite-phase — the
    old distance-watch channel-A-only drive was effectively half-drive),
    LED-matrix animation and motor_selftest, plus distance streaming, vibro
    rhythm + manual pulse, hot-plug retry for all modules, the 2 s failsafe
    (new for the wheel — it previously kept spinning if the app died), and
    2 Hz dashboard telemetry with signed duty. Self-test stream renamed to
    selftest_telemetry to free motor_telemetry for the dashboard.
    Python: distance-watch's policy/dashboard layer (presence -> vibro,
    eve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
    [app.js, main.py, sketch.ino]
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2026-08-07 Port v3's merged firmware into board/distance-watch
    board/distance-watch is now the v3 merged cane app (was board/
    qcane-wheel there): all three Modulinos — wheel with cross-channel
    opposite-phase drive (the motor spans terminals 1A<->2A), vibro rhythm
    on obstacle presence, distance streaming — plus the QCane Link
    dashboard (per-module cards, live current/voltage graphs, manual
    spin/stop/buzz + clear-graphs buttons, event log), LED-matrix wheel
    animation, motor self-test, and the 2 s failsafe.
    App identity stays "Distance Watch" to match the NUS peripheral name
    qhackGPS pairs with; its AVOID LEFT / AVOID RIGHT / CLEAR texts steer
    the wheel at full scale. ble-bridge/ updated to the v3 ve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
    [app.js, main.py, sketch.ino]
2026-08-07 Steer the wheel on route turns + deterministic on-board avoidance
    Phone (qhackGPS): the NUS mirror now streams full steering instead of
    only obstacle dodges — AVOID LEFT/RIGHT while dodging, TURN LEFT/RIGHT
    <deg> when the route itself bends (5-degree buckets, 15-degree
    deadband), CLEAR when aligned. A 90-degree corner starts the wheel
    turning the moment guidance calls it.
    Board: the text parser understands TURN <side> <deg> and scales wheel
    speed by the angle (>=75->5, 45..74->4, 30..44->3, else 2); STRAIGHT
    joins the stop words. New deterministic avoidance state machine for
    phone-less operation: obstacle inside the threshold -> turn away
    (default right, full speed) while it is present ->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
    [MainActivity.kt, main.py]
2026-08-07 Shepherd-inspired steering + haptics: ramps, urgency, grading, hysteresis
    Four upgrades lifted from the Shepherd smart cane, implemented by one
    focused agent each:
    1. Distance-graded vibro (parking-sensor rhythm): pulse period tightens
    linearly from 700 ms at the presence threshold to 250 ms near the
    stop tier, and goes continuous at/below 250 mm ("stop now").
    set_vibro now carries the period; the sketch honors it, with the
    continuous mode still built from self-terminating buzzes.
    2. Presence hysteresis + debounce: enter at the threshold, release only
    100 mm beyond it, both flips requiring 2 consecutive readings — an
    object hovering at the boundary can no longer chatter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
    [main.py, sketch.ino]
2026-08-07 Add heading calibration + routing-mode toggle, make route failures loud
    Two new FABs on the map screen:
    - Direction calibration (amber when a trim is active): align the compass
    to GPS course over ground while walking, or nudge +/-5 by hand; Reset
    clears the trim and re-registers the sensor listener so the smoothing
    state restarts from the next raw sample. Trim persists and is applied
    at the single trueHeading site, so the arrow, marker, Arduino frames
    and cane wheel all inherit it.
    - MAP/LINE toggle: Google walking directions vs straight-line bearing,
    persisted. The HUD now separates "straight line" (chosen) from
    "no route - straight line" (Directions had nothing).
    fetchWalk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
    [MainActivity.kt]
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2026-08-07 Full-speed-only wheel, spoken guidance (TTS), areamap-integration scope
    Board: all speed grading removed — TURN angles, phone/daemon speed
    hints, and dodge-urgency tiers are ignored; every spin commands 100%
    duty (WHEEL_SPEED = 5), with the sketch's leaky integrator still
    providing the ramp. Also restores the wheel-stop on NUS phone
    disconnect, which had regressed in the qcane-wheel merge.
    Phone (qhackGPS): new feedback/SpeechFeedback.kt (system TTS, trimmed
    from v3's) + guidance announcements from the same GuidanceBus every
    exporter reads: obstacle appears -> "Stop. Obstacle ahead, X meters.
    Step left/right." (interrupts, urgent register); path clear, route
    turns in 15-degree buckets rat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
    [MainActivity.kt, main.py]
2026-08-07 Wheel turns hard until the phone deems straight; TTS speaks transitions only
    The cane steer stream drops its 15-degree deadband: from the moment
    guidance calls a turn, the wheel drives 100% in that direction and keeps
    driving until the aligned hysteresis flips routeDirection to STRAIGHT
    (-> CLEAR). Degrees still ride along for the dashboard only.
    Spoken guidance no longer repeats: turn prompts fire only on a
    direction transition (left/right/straight), never on degree drift, and
    drop the degree readout ("Turn left." not "Turn left, about 40
    degrees." every few seconds). Obstacle, arrival, and cane-link lines
    were already transition-gated.
    [MainActivity.kt]
2026-08-07 Firmware pins every spin to 100% duty; dashboard arrow-key driving
    Sketch: drop the 1-5 SPEED_PERCENT table and the leaky-integrator ramp —
    set_wheel now steps the H-bridge straight to full-scale opposite-phase
    drive (or stop), ignoring the speed argument; motor_selftest drives full
    scale too. Failsafe and wire arity unchanged.
    Dashboard: hold arrow-left/right to spin (release stops), down/Space
    stops, up buzzes; lost focus stops the wheel. Speed row and hints now
    say full-scale-only.
    [app.js, main.py, sketch.ino]
2026-08-07 Phone is the only steering authority; TTS for every turn + dashboard buttons
    Board: delete the on-board auto-avoid state machine — obstacle presence
    only streams to the phone ({"mm","p"} over NUS, pushed instantly on a
    flip), and the wheel moves solely on the phone's AVOID/TURN/CLEAR texts
    (or the dashboard). Dashboard button presses (spin/stop/buzz, incl. the
    arrow keys) queue a {"say":...} line the bridge notifies to the phone.
    Phone: obstacle announcements now name the commanded turn ("Stop.
    Obstacle ahead, 0.8 meters. Turning left."), "Path clear." re-arms the
    route direction so the next instruction is always spoken, and incoming
    {"say":...} lines from the board are read aloud.
    Co-Au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
    [MainActivity.kt, main.py]
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2026-08-07 Hardware: real CAD, JGA25 drive, accurate costs; README rewrite
    Adds the six print-ready assemblies and their renders, and rewrites the
    three hardware docs plus the README around what the design actually is
    now rather than a specification of what it might become.
    CAD (Hardware/CAD/): omni wheel, main frame, hub mount + cover,
    electronics housing + cover, distance mount, S25 Ultra phone mount, Anker
    737 battery mount. Renders for five of them. Marked print-ready but NOT
    yet printed or fit-checked -- roller clearance on the print-in-place wheel
    is printer-dependent and will likely need an iteration.
    Drive train specified: JGA25-370 12 V geared motor on a 4 mm D-shaft,
    powered from a USB-C PD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
    [Anker 737 Power Bank - Battery Mount.stl, Hub Mount - Hub Cover.stl, Main.stl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]
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

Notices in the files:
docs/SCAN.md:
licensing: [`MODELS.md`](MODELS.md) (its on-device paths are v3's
